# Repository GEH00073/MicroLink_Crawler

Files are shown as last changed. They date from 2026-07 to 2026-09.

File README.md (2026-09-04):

# MicroLink Crawler

English | [日本語](README_ja.md)

**[Grand Prize Winner — M5Stack Global Innovation Contest 2026](https://m5stack.com/global-innovation-contest-2026/results)**

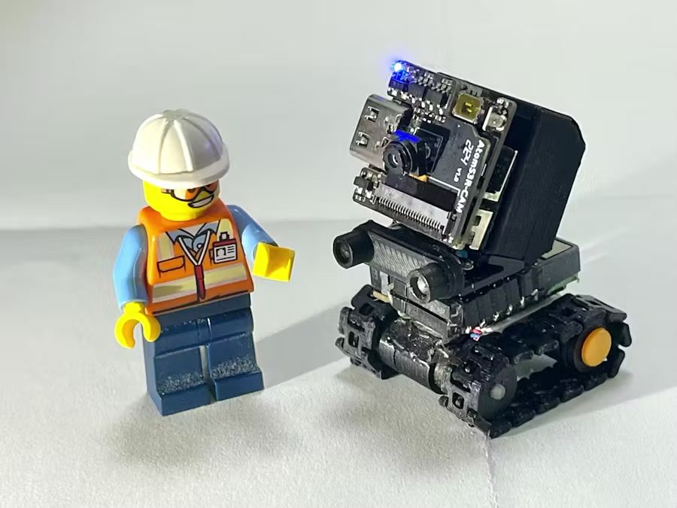
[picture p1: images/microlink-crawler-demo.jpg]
MicroLink Crawler demonstration photo


[▶ Watch the demo video on YouTube](https://www.youtube.com/watch?v=ZiZfx9JVto8)

MicroLink Crawler is a pocket-sized FPV exploration rover centred on a **30 × 30 mm crawler drive module** and 7 mm-wide, 3D-printed linked tracks. A detachable AtomS3R-CAM provides FPV video, orientation data, and red-object detection; an M5Stack Core2 acts as the remote monitor and an Atom JoyStick as the wireless controller.

This repository is a project archive, not a complete reproduction manual. Mechanical fit, printing results, and electronic assembly can require adjustment for the parts and tools in use.

## Highlights

- 30 × 30 mm crawler drive module
- Functional 7 mm-wide 3D-printed linked tracks
- 6 mm-diameter planetary geared motors
- Detachable AtomS3R-CAM module
- Live MJPEG FPV video
- Real-time heading and tilt display on Core2
- Red-object detection with a bounding box and centre coordinates
- Wireless operation with Atom JoyStick
- The complete system fits in a book-sized carrying case

## System overview

```mermaid
flowchart TB
  Joy["Atom JoyStick<br/>Controller"] -->|"ESP-NOW / ch 1"| Pico["M5Stamp Pico<br/>Crawler control"]
  Pico --> Motors["Two geared motors<br/>Micro linked tracks"]
  Camera["AtomS3R-CAM<br/>FPV + IMU + detection"] -->|"MJPEG / Wi-Fi AP ch 3"| Core2["M5Stack Core2<br/>Remote monitor"]
  Camera -->|"ESP-NOW / ch 3"| Core2
```

The system separates two wireless functions: Atom JoyStick sends crawler-control packets to Stamp Pico over ESP-NOW on Wi-Fi channel 1, while AtomS3R-CAM provides the camera/Core2 function on channel 3. The camera serves MJPEG through its access point and sends IMU data to Core2 through ESP-NOW.

Read more: [system overview](docs/system-overview.md).

## Micro linked tracks

The 7 mm-wide linked tracks were developed by progressively reducing a larger prototype. They were made with a standard 0.4 mm-nozzle FDM printer. A centre guide groove and openings that engage the sprocket teeth help keep the track aligned, transfer torque, and reduce derailment or slip. The drive uses 6 mm-diameter planetary geared motors.

Read more: [micro linked tracks](docs/micro-linked-track.md).

## FPV, orientation, and red-object detection

The AtomS3R-CAM serves MJPEG video to Core2 through its Wi-Fi access point. Its IMU data is sent to Core2 over ESP-NOW, where heading and tilt are displayed. The camera firmware also detects red objects and sends the detection-box centre coordinates.

The Core2 monitor disables Wi-Fi power saving while streaming and favours the latest decoded frame when old frames must be dropped. On the camera side, a 350 ms TCP send timeout limits how long a slow client can hold up streaming work. These measures are intended to reduce prolonged video stalls.

Read more: [vision and telemetry](docs/vision-and-telemetry.md).

## Firmware

Each directory below is an independent PlatformIO project.

| Directory | Hardware | Role | Communication partner |
| --- | --- | --- | --- |
| `Firmware/MC_stamp_pico_crawler` | M5Stamp Pico | Controls the two motors and lights | Atom JoyStick |
| `Firmware/MC_AtomJoystick` | AtomS3 with Atom JoyStick Base | Remote control | M5Stamp Pico |
| `Firmware/MC_AtomS3R_CAM_GC0308_gylo` | AtomS3R-CAM with GC0308 | FPV, IMU, and red-object detection | Core2 |
| `Firmware/MC_Core2_cam_reciever_AP` | M5Stack Core2 | Video and orientation-information display | AtomS3R-CAM |

Read more: [firmware overview](docs/firmware-overview.md).

## 3D data

[`3D_Printer_Data/`](3D_Printer_Data/) contains STL files for printing and Fusion 360 F3D files for design inspection or editing. These are the design data used for the award project and are provided as structural reference data, not as a complete fabrication guide. Printer, material, and dimensional tolerances can require adjustment.

Read more: [3D data guide](3D_Printer_Data/README.md) and [development story](docs/development-story.md).

## Repository layout

| Path | Contents |
| --- | --- |
| `Firmware/` | Four independent PlatformIO firmware projects |
| `3D_Printer_Data/` | STL and Fusion 360 F3D mechanical design data |
| `docs/` | Project, track, vision, development, and firmware notes |

## Links and questions

- [M5Stack Global Innovation Contest 2026 Results](https://m5stack.com/global-innovation-contest-2026/results)
- [Hackster.io project page](https://www.hackster.io/user2729037/microlink-crawler-379ff1)
- [X: @GEH00073](https://x.com/GEH00073)
- [GitHub Issues](https://github.com/GEH00073/MicroLink_Crawler/issues/new)

Please use [GitHub Issues](https://github.com/GEH00073/MicroLink_Crawler/issues/new) first for technical questions so that answers can help other readers. Following or sending a direct message on X is optional.

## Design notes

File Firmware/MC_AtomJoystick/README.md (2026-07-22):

# AtomJoystick Firmware

Dedicated M5AtomS3 controller firmware for the MicroLink Crawler.

## Operation

The firmware starts directly in crawler control mode. It reads the Atom
JoyStick Base and sends BugC-compatible ESP-NOW broadcast packets at 20 Hz on
Wi-Fi channel 1. There is no OTA mode, vehicle-selection menu, Toio support,
or controller-side pairing procedure.

Use it with `MC_stamp_pico_crawler`. Power on both devices and begin control.

## Build and upload

Open this directory as a PlatformIO project, select the `m5stack-atoms3`
environment, and upload over USB.

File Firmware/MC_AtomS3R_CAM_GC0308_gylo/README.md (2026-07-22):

# AtomS3R Camera Transmitter

PlatformIO firmware for an AtomS3R with a GC0308 camera.

## Features

- Creates a Wi-Fi access point and serves an MJPEG stream at `/video`.
- Sends IMU data through ESP-NOW at 10 Hz.
- Detects red objects and draws a 2-pixel green bounding box at 10 Hz.
- Uses a bounded TCP send timeout so a slow client cannot stop camera capture
  or IMU transmission for several seconds.

## Network settings

| Setting | Value |
| --- | --- |
| SSID | `AtomS3R_CAM` |
| Password | `123456` |
| Wi-Fi channel | 3 |
| Access point address | `192.168.4.1` |
| Stream URL | `http://192.168.4.1/video` |

The Core2 monitor firmware is configured to use these same settings. Change
the `AP_SSID` and `AP_PASSWORD` constants in `src/main.cpp`, and make the
matching change in the Core2 firmware, if different credentials are required.

## Build and upload

Open this directory as a PlatformIO project and use the `m5stack-atoms3r`
environment. Upload over USB.

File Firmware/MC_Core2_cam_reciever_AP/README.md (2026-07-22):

# Core2 Camera Monitor

PlatformIO firmware for an M5Stack Core2 used as the MicroLink Crawler camera
monitor.

## Operation

The monitor connects to the AtomS3R camera access point and displays the MJPEG
stream from `http://192.168.4.1/video`. It also receives and displays IMU data
from the camera through ESP-NOW.

The expected camera network is:

| Setting | Value |
| --- | --- |
| SSID | `AtomS3R_CAM` |
| Password | `123456` |

Wi-Fi power saving is disabled while streaming. The receiver discards old
frames when necessary so the display follows the most recent decoded frame.

## Build and upload

Open this directory as a PlatformIO project, select the `m5stack-core2`
environment, and upload over USB.

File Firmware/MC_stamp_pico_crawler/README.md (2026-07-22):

# Stamp Pico Crawler Firmware

PlatformIO firmware for the M5Stamp Pico installed in the MicroLink Crawler.

## Control link

The crawler receives 25-byte BugC-compatible control packets through ESP-NOW
on Wi-Fi channel 1. `MC_AtomJoystick` sends these packets as broadcast frames,
so the joystick can control the crawler immediately after both devices are
powered on. No controller-side pairing menu or saved peer address is needed.

The packet carries rudder, throttle, aileron, elevator, four button states,
and a checksum. The crawler validates the packet length, destination, and
checksum before applying it.

## Build and upload

Open this directory as a PlatformIO project and upload it to the Stamp Pico
over USB.

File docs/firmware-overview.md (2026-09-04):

# Firmware overview

English | [日本語](firmware-overview_ja.md)

The repository contains four independent PlatformIO projects. Build and upload each project from its own directory.

| Project | Hardware | Main role | Communication partner |
| --- | --- | --- | --- |
| [`Firmware/MC_stamp_pico_crawler`](../Firmware/MC_stamp_pico_crawler/) | M5Stamp Pico | Receives BugC-compatible ESP-NOW control packets on channel 1; controls two motors and lights | `MC_AtomJoystick` |
| [`Firmware/MC_AtomJoystick`](../Firmware/MC_AtomJoystick/) | AtomS3 with Atom JoyStick Base | Sends BugC-compatible ESP-NOW control packets on channel 1 | `MC_stamp_pico_crawler` |
| [`Firmware/MC_AtomS3R_CAM_GC0308_gylo`](../Firmware/MC_AtomS3R_CAM_GC0308_gylo/) | AtomS3R with GC0308 camera | Camera access point, MJPEG FPV, IMU transmission, and red-object detection on channel 3 | `MC_Core2_cam_reciever_AP` |
| [`Firmware/MC_Core2_cam_reciever_AP`](../Firmware/MC_Core2_cam_reciever_AP/) | M5Stack Core2 | Receives and displays MJPEG video and IMU information | `MC_AtomS3R_CAM_GC0308_gylo` |

The control and camera systems are separate: do not confuse the crawler-control channel 1 with the camera/Core2 channel 3. Consult each project’s existing README and `platformio.ini` for its build configuration.

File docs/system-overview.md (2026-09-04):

# System overview

English | [日本語](system-overview_ja.md)

MicroLink Crawler combines a 30 × 30 mm crawler drive module, a detachable AtomS3R-CAM module, an Atom JoyStick controller, a Core2 monitor, and a book-sized carrying case for the complete system.

The drive-control and camera-monitor functions use separate Wi-Fi channels so their roles remain distinct:

| Path | Devices | Function |
| --- | --- | --- |
| Control | Atom JoyStick → M5Stamp Pico | ESP-NOW crawler control on channel 1 |
| Video | AtomS3R-CAM → Core2 | MJPEG through the camera access point on channel 3 |
| Telemetry | AtomS3R-CAM → Core2 | IMU data through ESP-NOW on channel 3 |

The Stamp Pico controls the two geared motors and lights. The camera module can be removed from the drive module; Core2 displays video and orientation information remotely.

See the [README](../README.md) for the system diagram and [firmware overview](firmware-overview.md) for project locations.

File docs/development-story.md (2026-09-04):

# Development story

English | [日本語](development-story_ja.md)

The public project description records the following development progression:

1. An initial larger linked-track prototype.
2. Progressive miniaturisation to a 7 mm-wide linked track.
3. Drive by 6 mm-diameter planetary geared motors.
4. Wireless crawler control with Stamp Pico and Atom JoyStick.
5. Detachable AtomS3R-CAM FPV capability.
6. Core2 display of video plus orientation information.
7. Red-object detection and centre-coordinate display.
8. A complete system that fits in a book-sized carrying case.
9. Entry in the M5Stack Global Innovation Contest 2026 and Grand Prize recognition.

The public sources and repository do not establish a detailed chronology, design motivation, failed experiments, or fabrication conditions beyond these points. Those subjects are intentionally not reconstructed here.

Sources: [M5Stack contest results](https://m5stack.com/global-innovation-contest-2026/results) and the [Hackster.io project page](https://www.hackster.io/user2729037/microlink-crawler-379ff1).

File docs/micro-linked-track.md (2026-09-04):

# Micro linked tracks

English | [日本語](micro-linked-track_ja.md)

The micro linked-track system was developed by progressively reducing a larger prototype until it reached a 7 mm track width. It is a functional track system printed with a standard 0.4 mm-nozzle FDM printer and driven by 6 mm-diameter planetary geared motors.

A guide groove along the centre of each track works with openings shaped for the sprocket teeth. Together, these features keep the track aligned, transmit drive torque, and reduce derailment or slip.

This document is a design note, not a complete manufacturing procedure. It does not prescribe material, print settings, tolerances, or an assembly sequence; those depend on the equipment and parts used.

See the [3D data guide](../3D_Printer_Data/README.md) for the supplied STL and F3D data, and the [development story](development-story.md) for the confirmed project progression.

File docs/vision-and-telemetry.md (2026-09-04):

# Vision and telemetry

English | [日本語](vision-and-telemetry_ja.md)

The detachable AtomS3R-CAM module creates a Wi-Fi access point on channel 3 and serves an MJPEG stream at `/video`. Core2 connects to that access point and displays the video.

The camera firmware sends IMU data through ESP-NOW on channel 3 at 10 Hz. Core2 uses that information to display heading and tilt. The camera also performs red-object detection; when a red object is detected, the system supplies a green detection box and its centre coordinates to the monitor.

Two implementation choices reduce visible latency or long pauses:

- Core2 disables Wi-Fi power saving while streaming and discards older frames when necessary so the latest decoded frame is preferred.
- The camera uses a 350 ms TCP send timeout, limiting how long a slow client can hold up streaming work.

For settings and build targets, see the [camera firmware README](../Firmware/MC_AtomS3R_CAM_GC0308_gylo/README.md) and [Core2 firmware README](../Firmware/MC_Core2_cam_reciever_AP/README.md).

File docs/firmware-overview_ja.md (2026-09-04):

# ファームウェア構成

[English](firmware-overview.md) | 日本語

リポジトリには4つの独立したPlatformIOプロジェクトがあります。各プロジェクトはそれぞれのディレクトリからビルド・書き込みを行います。

| プロジェクト | ハードウェア | 主な役割 | 通信相手 |
| --- | --- | --- | --- |
| [`Firmware/MC_stamp_pico_crawler`](../Firmware/MC_stamp_pico_crawler/) | M5Stamp Pico | チャンネル1でBugC互換ESP-NOW制御パケットを受信し、2台のモーターとライトを制御 | `MC_AtomJoystick` |
| [`Firmware/MC_AtomJoystick`](../Firmware/MC_AtomJoystick/) | AtomS3 + Atom JoyStick Base | チャンネル1でBugC互換ESP-NOW制御パケットを送信 | `MC_stamp_pico_crawler` |
| [`Firmware/MC_AtomS3R_CAM_GC0308_gylo`](../Firmware/MC_AtomS3R_CAM_GC0308_gylo/) | AtomS3R + GC0308カメラ | チャンネル3のカメラアクセスポイント、MJPEG FPV、IMU送信、赤色物体検出 | `MC_Core2_cam_reciever_AP` |
| [`Firmware/MC_Core2_cam_reciever_AP`](../Firmware/MC_Core2_cam_reciever_AP/) | M5Stack Core2 | MJPEG映像とIMU情報を受信・表示 | `MC_AtomS3R_CAM_GC0308_gylo` |

走行制御系とカメラ系は別です。走行制御のチャンネル1と、カメラ／Core2のチャンネル3を混同しないでください。ビルド設定は各プロジェクトの既存READMEおよび`platformio.ini`を参照してください。

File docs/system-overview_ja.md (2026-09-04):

# システム構成

[English](system-overview.md) | 日本語

MicroLink Crawlerは、30 × 30 mmのクローラー走行モジュール、着脱可能なAtomS3R-CAMモジュール、Atom JoyStickコントローラー、Core2モニター、およびシステム全体を収納するブックサイズの携帯ケースで構成されます。

走行制御とカメラ・モニターの機能は、それぞれの役割を分けるため別のWi-Fiチャンネルを使用します。

| 経路 | デバイス | 機能 |
| --- | --- | --- |
| 走行制御 | Atom JoyStick → M5Stamp Pico | チャンネル1のESP-NOWによる走行制御 |
| 映像 | AtomS3R-CAM → Core2 | チャンネル3のカメラアクセスポイント経由MJPEG |
| テレメトリー | AtomS3R-CAM → Core2 | チャンネル3のESP-NOWによるIMU情報 |

Stamp Picoは2台のギヤードモーターとライトを制御します。カメラモジュールは走行モジュールから取り外せ、Core2は遠隔で映像と姿勢情報を表示します。

システム図は[README](../README_ja.md)、プロジェクトの配置は[ファームウェア構成](firmware-overview_ja.md)を参照してください。

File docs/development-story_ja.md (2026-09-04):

# 開発の経緯

[English](development-story.md) | 日本語

公開されている作品説明から、次の開発の流れを確認できます。

1. 大きなリンク式履帯による初期試作。
2. 7 mm幅のリンク式履帯までの段階的な小型化。
3. 6 mm径の遊星ギヤードモーターによる駆動。
4. Stamp PicoとAtom JoyStickによる無線走行制御。
5. 着脱可能なAtomS3R-CAMによるFPV機能。
6. 映像と姿勢情報をCore2へ表示。
7. 赤色物体検出と中心座標表示。
8. システム全体をブックサイズの携帯ケースへ収納。
9. M5Stack Global Innovation Contest 2026への応募とGrand Prize受賞。

公開情報とリポジトリからは、これらより詳細な時系列、設計動機、失敗した試作、製作条件までは確認できません。これらの事項は推測で再構成していません。

情報源: [M5Stackコンテスト結果](https://m5stack.com/global-innovation-contest-2026/results)および[Hackster.io作品ページ](https://www.hackster.io/user2729037/microlink-crawler-379ff1)。

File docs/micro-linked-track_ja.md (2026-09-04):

# マイクロリンク式履帯

[English](micro-linked-track.md) | 日本語

マイクロリンク式履帯は、大型試作を段階的に縮小し、7 mm幅に到達するまで開発されました。一般的な0.4 mmノズルのFDMプリンターで造形した、機能する履帯システムであり、6 mm径の遊星ギヤードモーターで駆動します。

各履帯の中央ガイド溝と、スプロケット歯に合わせた開口部が連携します。これにより履帯の位置を保ち、駆動トルクを伝達して、外れや空転を抑えます。

本書は設計の補足であり、完全な製作手順ではありません。材料、印刷設定、寸法公差、組み立て順序は、使用する機器と部品に依存するため規定していません。

収録したSTL・F3Dデータは[3Dデータガイド](../3D_Printer_Data/README_ja.md)、確認済みの開発経緯は[開発の経緯](development-story_ja.md)を参照してください。

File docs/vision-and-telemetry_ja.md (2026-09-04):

# FPV・姿勢情報・赤色物体検出

[English](vision-and-telemetry.md) | 日本語

着脱可能なAtomS3R-CAMモジュールはチャンネル3でWi-Fiアクセスポイントを作成し、`/video`でMJPEGストリームを配信します。Core2はこのアクセスポイントに接続して映像を表示します。

カメラのファームウェアは、チャンネル3のESP-NOWでIMU情報を10 Hzで送信します。Core2はこの情報を用いて方位と傾きを表示します。カメラは赤色物体も検出し、検出時には緑色の検出枠と中心座標をモニターへ送ります。

可視遅延や長い停止を抑えるため、実装には次の処理があります。

- Core2はストリーミング中にWi-Fi省電力を無効化し、必要に応じて古いフレームを捨てて最新のデコード済みフレームを優先します。
- カメラは350 msのTCP送信タイムアウトを使用し、遅いクライアントがストリーミング処理を占有する時間を制限します。

設定とビルド対象は、[カメラファームウェアREADME](../Firmware/MC_AtomS3R_CAM_GC0308_gylo/README.md)および[Core2ファームウェアREADME](../Firmware/MC_Core2_cam_reciever_AP/README.md)を参照してください。

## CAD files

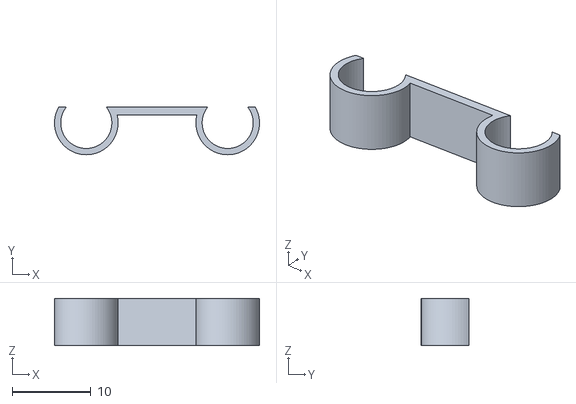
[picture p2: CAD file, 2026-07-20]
3D_Printer_Data/chassis.stl
26.1 x 6.05 x 6.00

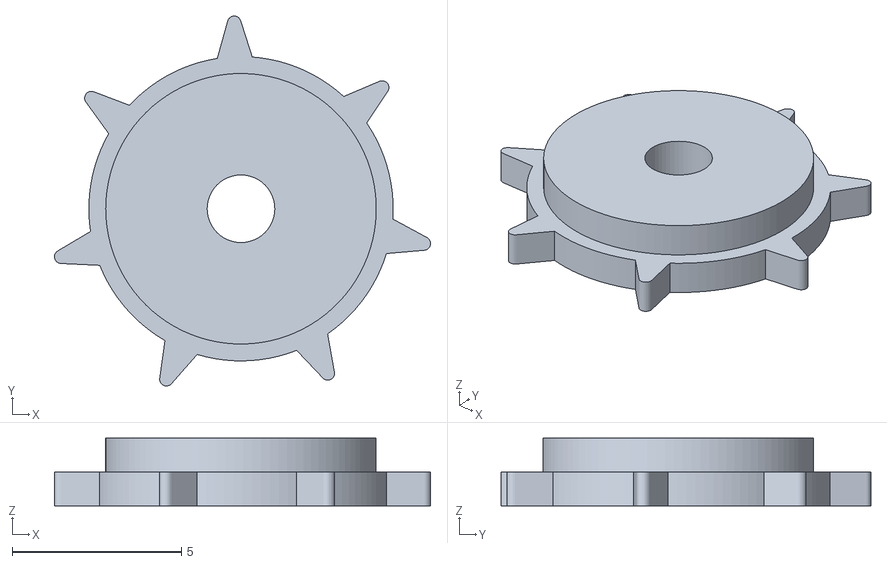
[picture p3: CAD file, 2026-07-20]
3D_Printer_Data/sprocket_9mm.stl
11.1 x 10.9 x 2.00

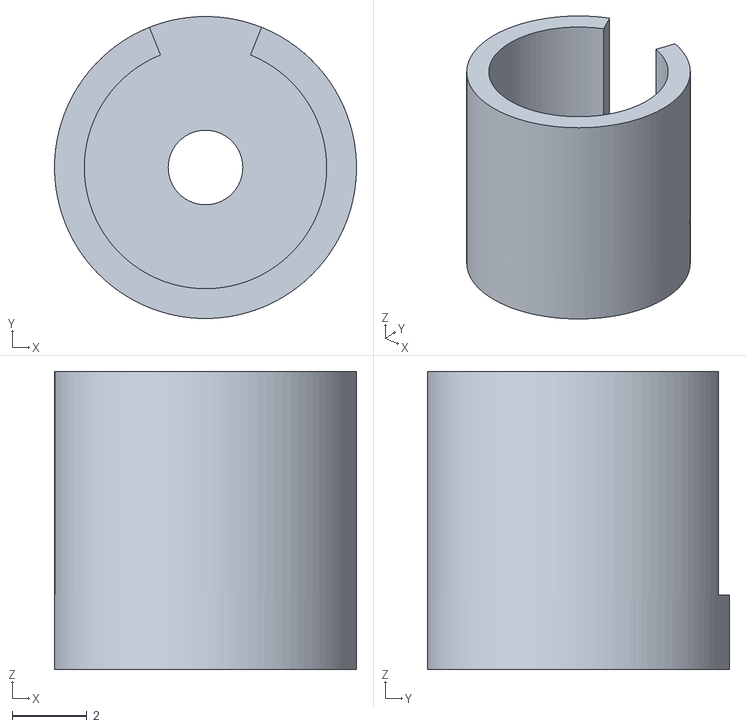
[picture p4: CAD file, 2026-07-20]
3D_Printer_Data/motor_bottom.stl
8.10 x 8.10 x 8.00

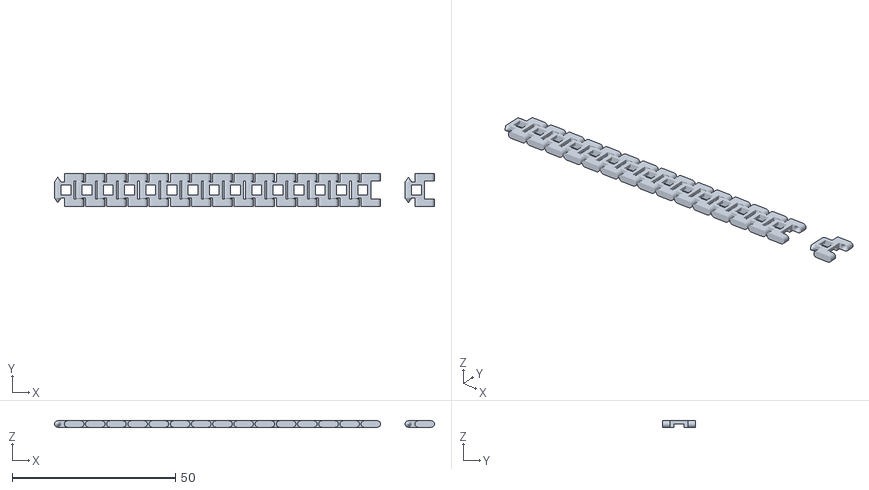
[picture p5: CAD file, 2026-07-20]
3D_Printer_Data/hinge_s.stl
116.5 x 10.0 x 2.00

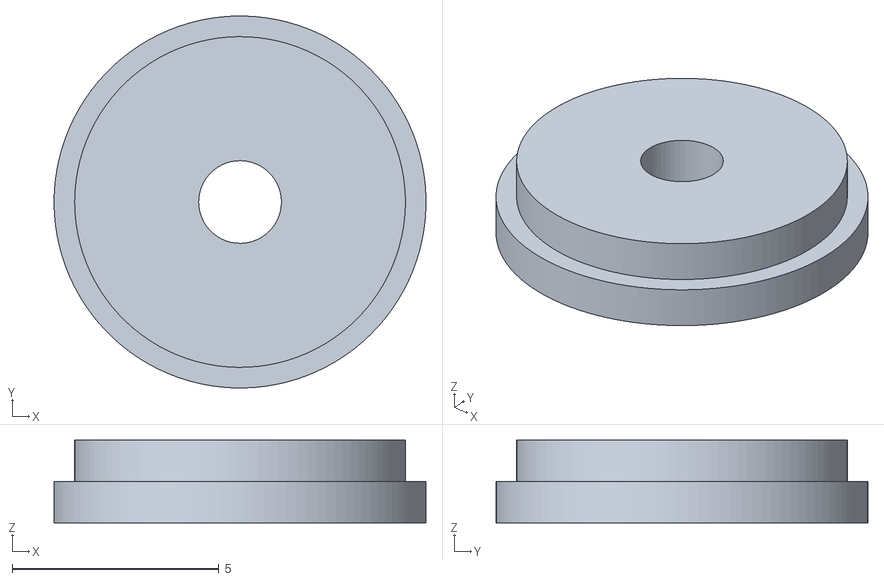
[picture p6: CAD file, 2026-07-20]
3D_Printer_Data/sprocket_9mm_2.stl
9.00 x 9.00 x 2.00

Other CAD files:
3D_Printer_Data/chassis.f3d
3D_Printer_Data/hinge_s.f3d
3D_Printer_Data/motor_bottom.f3d
3D_Printer_Data/sprocket_9mm.f3d
3D_Printer_Data/sprocket_9mm_2.f3d

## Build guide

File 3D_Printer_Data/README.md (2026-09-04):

# MicroLink Crawler 3D Data

English | [日本語](README_ja.md)

This directory contains the STL printing files and Fusion 360 F3D design files used for the MicroLink Crawler award project. STL files are intended for printing; F3D files are provided for design inspection or editing.

These files are structural reference data, not a complete fabrication manual. Printing and assembly can require adjustment for the printer, material, component tolerances, and tools in use.

| File | Format | Description |
| --- | --- | --- |
| `chassis.stl` / `chassis.f3d` | STL / F3D | Chassis design data |
| `hinge_s.stl` / `hinge_s.f3d` | STL / F3D | Hinge design data |
| `motor_bottom.stl` / `motor_bottom.f3d` | STL / F3D | Motor-bottom design data |
| `sprocket_9mm.stl` / `sprocket_9mm.f3d` | STL / F3D | Sprocket design data |
| `sprocket_9mm_2.stl` / `sprocket_9mm_2.f3d` | STL / F3D | Sprocket design data |

For the project context and track design notes, see the [root README](../README.md) and [micro linked tracks](../docs/micro-linked-track.md).

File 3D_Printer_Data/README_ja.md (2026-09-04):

# MicroLink Crawler 3Dデータ

[English](README.md) | 日本語

このディレクトリには、MicroLink Crawler受賞作品で使用したSTL造形データとFusion 360 F3D設計データを収録しています。STLは造形用、F3Dは設計確認・編集用のデータです。

これらは構造を確認するための参考データであり、完全な製作マニュアルではありません。プリンター、材料、部品の寸法公差、工具に応じて、造形や組み立ての調整が必要になる場合があります。

| ファイル | 形式 | 説明 |
| --- | --- | --- |
| `chassis.stl` / `chassis.f3d` | STL / F3D | シャーシ設計データ |
| `hinge_s.stl` / `hinge_s.f3d` | STL / F3D | ヒンジ設計データ |
| `motor_bottom.stl` / `motor_bottom.f3d` | STL / F3D | モーター下部の設計データ |
| `sprocket_9mm.stl` / `sprocket_9mm.f3d` | STL / F3D | スプロケット設計データ |
| `sprocket_9mm_2.stl` / `sprocket_9mm_2.f3d` | STL / F3D | スプロケット設計データ |

作品全体と履帯設計の説明は、[ルートREADME](../README_ja.md)および[マイクロリンク式履帯](../docs/micro-linked-track_ja.md)を参照してください。

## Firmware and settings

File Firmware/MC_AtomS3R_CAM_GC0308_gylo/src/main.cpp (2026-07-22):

#include <Wire.h>
#include <WiFi.h>
#include <esp_http_server.h>
#include <esp_camera.h>
#include <esp_now.h>
#include <lwip/sockets.h>

// ==== BMI270 (Bosch API) ====
#include "bmi270.h"
#include "bmi2.h"

#define BMI270_ADDR 0x68

struct bmi2_dev bmi2_dev;
struct bmi2_sens_config sens_cfg[2];
struct bmi2_sens_data sensor_data[2];

// ==== Wi-Fi AP ====
// Core2 receiver connects directly to this access point.
const char *AP_SSID = "AtomS3R_CAM";
const char *AP_PASSWORD = "123456";
constexpr uint8_t WIFI_CHANNEL = 3;
const IPAddress AP_IP(192, 168, 4, 1);
const IPAddress AP_GATEWAY(192, 168, 4, 1);
const IPAddress AP_SUBNET(255, 255, 255, 0);

typedef struct struct_message {
  int16_t x;
  int16_t y;
  float ax, ay, az;
  float gx, gy, gz;
} struct_message;
struct_message myData;

uint8_t broadcastAddress[] = {0xFF,0xFF,0xFF,0xFF,0xFF,0xFF};

float ax, ay, az;
float gx, gy, gz;
float cx_smooth = 0;
float cy_smooth = 0;
bool first_point = true;
unsigned long last_imu_send_ms = 0;
constexpr unsigned long IMU_SEND_INTERVAL_MS = 100; // 10 Hz
unsigned long last_box_draw_ms = 0;
constexpr unsigned long BOX_DRAW_INTERVAL_MS = 100; // 10 Hz
constexpr bool ENABLE_RED_DETECTION = true;
constexpr long STREAM_SEND_TIMEOUT_US = 350000; // TCP詰まりを350 msで打ち切る
portMUX_TYPE imu_data_mux = portMUX_INITIALIZER_UNLOCKED;

volatile uint32_t diag_espnow_ok = 0;
volatile uint32_t diag_espnow_fail = 0;
uint32_t diag_stream_frames = 0;
uint32_t diag_stream_bytes = 0;
uint32_t diag_max_encode_us = 0;
uint32_t diag_max_send_us = 0;
uint32_t diag_last_frame_ms = 0;
uint32_t diag_last_report_ms = 0;

// ==== Bosch API用のI2Cラッパ ====

// 書き込み
BMI2_INTF_RETURN_TYPE i2c_reg_write(uint8_t reg_addr, const uint8_t *reg_data, uint32_t length, void *intf_ptr) {
  Wire.beginTransmission(BMI270_ADDR);
  Wire.write(reg_addr);
  Wire.write(reg_data, length);
  return (Wire.endTransmission() == 0) ? BMI2_INTF_RET_SUCCESS : BMI2_E_COM_FAIL;
}

// 読み込み
BMI2_INTF_RETURN_TYPE i2c_reg_read(uint8_t reg_addr, uint8_t *reg_data, uint32_t length, void *intf_ptr) {
  Wire.beginTransmission(BMI270_ADDR);
  Wire.write(reg_addr);
  Wire.endTransmission(false);
  Wire.requestFrom((uint16_t)BMI270_ADDR, (uint8_t)length);
  for (uint32_t i = 0; i < length; i++) {
    reg_data[i] = Wire.read();
  }
  return BMI2_INTF_RET_SUCCESS;
}

void bmi2_delay_us(uint32_t period, void *intf_ptr) {
  delayMicroseconds(period);
}

// ==== BMI270 初期化 ====
void init_bmi270() {
  bmi2_dev.intf = BMI2_I2C_INTF;
  bmi2_dev.read = i2c_reg_read;
  bmi2_dev.write = i2c_reg_write;
  bmi2_dev.delay_us = bmi2_delay_us;
  bmi2_dev.intf_ptr = NULL;
  bmi2_dev.read_write_len = 32;
  bmi2_dev.config_file_ptr = NULL;

  int8_t rslt = bmi270_init(&bmi2_dev);
  if (rslt != BMI2_OK) {
    Serial.printf("BMI270 init failed: %d\n", rslt);
    return;
  }

  uint8_t sens_list[2] = { BMI2_ACCEL, BMI2_GYRO };
  bmi2_sensor_enable(sens_list, 2, &bmi2_dev);

  sens_cfg[0].type = BMI2_ACCEL;
  sens_cfg[1].type = BMI2_GYRO;
  bmi2_get_sensor_config(sens_cfg, 2, &bmi2_dev);

  sens_cfg[0].cfg.acc.odr = BMI2_ACC_ODR_100HZ;
  sens_cfg[0].cfg.acc.range = BMI2_ACC_RANGE_8G;
  sens_cfg[1].cfg.gyr.odr = BMI2_GYR_ODR_100HZ;
  sens_cfg[1].cfg.gyr.range = BMI2_GYR_RANGE_2000;

  bmi2_set_sensor_config(sens_cfg, 2, &bmi2_dev);
  Serial.println("BMI270 init OK");
}

// ==== 加速度・ジャイロ読み出し（最新ライブラリ対応） ====
void readAccelGyro() {
  int8_t rslt;

  // LSB換算値
  const float ACC_LSB_8G   = 8.0f / 32768.0f;     // ±2G
  const float GYR_LSB_2000 = 2000.0f / 32768.0f;  // ±2000 dps

  // 加速度取得
  rslt = bmi2_get_sensor_data(&sensor_data[0], &bmi2_dev);
  if (rslt != BMI2_OK) return;
  ax = sensor_data[0].acc.x * ACC_LSB_8G;
  ay = sensor_data[0].acc.y * ACC_LSB_8G;
  az = sensor_data[0].acc.z * ACC_LSB_8G;

  // ジャイロ取得
  rslt = bmi2_get_sensor_data(&sensor_data[1], &bmi2_dev);
  if (rslt != BMI2_OK) return;
  gx = sensor_data[1].gyr.x * GYR_LSB_2000;
  gy = sensor_data[1].gyr.y * GYR_LSB_2000;
  gz = sensor_data[1].gyr.z * GYR_LSB_2000;
}

// ==== ESP-NOW送信コールバック ====
void OnDataSent(const uint8_t *mac_addr, esp_now_send_status_t status) {
  if (status == ESP_NOW_SEND_SUCCESS) diag_espnow_ok++;
  else diag_espnow_fail++;
}

// ==== MJPEG ====
#define PART_BOUNDARY "123456789000000000000987654321"
static const char* _STREAM_CONTENT_TYPE = "multipart/x-mixed-replace;boundary=" PART_BOUNDARY;
static const char* _STREAM_BOUNDARY = "\r\n--" PART_BOUNDARY "\r\n";
static const char* _STREAM_PART = "Content-Type: image/jpeg\r\nContent-Length: %u\r\n\r\n";

uint8_t* out_jpg   = NULL;
size_t out_jpg_len = 0;

// ==== 緑の2画素枠を描画 ====
void draw_green_rect(camera_fb_t *fb, int x_min, int y_min, int x_max, int y_max) {
  if (x_min < 0 || y_min < 0 || x_max >= fb->width || y_max >= fb->height) return;
  uint16_t green = (63 << 5);
  for (int thickness = 0; thickness < 2; ++thickness) {
    const int left_x = x_min + thickness;
    const int right_x = x_max - thickness;
    const int top_y = y_min + thickness;
    const int bottom_y = y_max - thickness;
    if (left_x > right_x || top_y > bottom_y) break;

    for (int x = left_x; x <= right_x; ++x) {
      size_t top = (top_y * fb->width + x) * 2;
      size_t bottom = (bottom_y * fb->width + x) * 2;
      fb->buf[top] = fb->buf[bottom] = green >> 8;
      fb->buf[top + 1] = fb->buf[bottom + 1] = green & 0xFF;
    }
    for (int y = top_y; y <= bottom_y; ++y) {
      size_t left = (y * fb->width + left_x) * 2;
      size_t right = (y * fb->width + right_x) * 2;
      fb->buf[left] = fb->buf[right] = green >> 8;
      fb->buf[left + 1] = fb->buf[right + 1] = green & 0xFF;
    }
  }
}

// ==== 色検出処理 ====
void Color_detection(camera_fb_t *fb){
  int16_t detected_x = 0;
  int16_t detected_y = 0;
  if (ENABLE_RED_DETECTION) {
  int count[] = {0,0,0,0};
  int height = fb->height;
  int width  = fb->width;
  int y_min = 1000, y_max = -1000;
  int x_min = 1000, x_max = -1000;

  for(int y=0;y<height;y++){
    for(int x=0;x<width;x++){
      size_t idx=(y*width+x)*2;
      uint16_t pixel=(fb->buf[idx]<<8)|(fb->buf[idx+1]);
      uint8_t r=((pixel>>11)&0x1F)<<3;
      uint8_t g=((pixel>>5)&0x3F)<<2;
      uint8_t b=(pixel&0x1F)<<3;

      if(r>200 && g<100 && b<100){
        if(x<width/3) count[0]++; else if(x>width/3*2) count[1]++;
        if(y<height/3) count[2]++; else if(y>height/3*2) count[3]++;

        if(x_min>x) x_min=x; if(x_max<x) x_max=x;
        if(y_min>y) y_min=y; if(y_max<y) y_max=y;
      }
    }
  }

  if(x_min<x_max && y_min<y_max){
    int cx=(x_min+x_max)/2;
    int cy=(y_min+y_max)/2;

    if(first_point){
      cx_smooth=cx; cy_smooth=cy; first_point=false;
    } else {
      float alpha=0.2;
      cx_smooth=cx_smooth*(1-alpha)+cx*alpha;
      cy_smooth=cy_smooth*(1-alpha)+cy*alpha;
    }
    if (millis() - last_box_draw_ms >= BOX_DRAW_INTERVAL_MS) {
      draw_green_rect(fb, x_min, y_min, x_max, y_max);
      last_box_draw_ms = millis();
    }
    detected_x=(int)cx_smooth;
    detected_y=(int)cy_smooth;
  }
  }

  portENTER_CRITICAL(&imu_data_mux);
  myData.x = detected_x;
  myData.y = detected_y;
  portEXIT_CRITICAL(&imu_data_mux);
}

// HTTP送信が停止してもIMU/ESP-NOWを10 Hzで継続する。
void serviceImuEspNow() {
  const unsigned long now = millis();
  if (now - last_imu_send_ms < IMU_SEND_INTERVAL_MS) return;
  last_imu_send_ms = now;

  readAccelGyro();

  struct_message packet;
  portENTER_CRITICAL(&imu_data_mux);
  myData.ax=ax; myData.ay=ay; myData.az=az;
  myData.gx=gx; myData.gy=gy; myData.gz=gz;
  packet = myData;
  portEXIT_CRITICAL(&imu_data_mux);

  if (esp_now_send(broadcastAddress,(uint8_t*)&packet,sizeof(packet)) != ESP_OK) {
    diag_espnow_fail++;
  }
}

// ==== ストリームハンドラ ====
static esp_err_t stream_handler(httpd_req_t *req){
  camera_fb_t *fb=NULL;
  esp_err_t res=ESP_OK;
  char part_buf[64];

  res=httpd_resp_set_type(req,_STREAM_CONTENT_TYPE);
  if(res!=ESP_OK) return res;

  // Core2側のTCP受信が詰まった場合、何秒もカメラ処理を止めず接続を閉じる。
  const int sockfd = httpd_req_to_sockfd(req);
  struct timeval send_timeout = {};
  send_timeout.tv_usec = STREAM_SEND_TIMEOUT_US;
  if (setsockopt(sockfd, SOL_SOCKET, SO_SNDTIMEO,
                 &send_timeout, sizeof(send_timeout)) != 0) {
    Serial.printf("[CAM][WARN] SO_SNDTIMEO failed errno=%d\n", errno);
  }

  const int frame_interval_ms=1000/30;

  while(true){
    unsigned long start_time=millis();
    if (diag_last_frame_ms != 0 && start_time - diag_last_frame_ms >= 500) {
      Serial.printf("[CAM][FRAME_GAP] gap=%lums heap=%u psram=%u\n",
                    start_time - diag_last_frame_ms, ESP.getFreeHeap(), ESP.getFreePsram());
    }
    diag_last_frame_ms = start_time;
    fb=esp_camera_fb_get();
    if(!fb){Serial.println("Camera capture failed"); res=ESP_FAIL;}
    
    Color_detection(fb);

    const uint32_t encode_start_us = micros();
    free(out_jpg);
    bool jpeg_converted=frame2jpg(fb,80,&out_jpg,&out_jpg_len);
    const uint32_t encode_us = micros() - encode_start_us;
    if (encode_us > diag_max_encode_us) diag_max_encode_us = encode_us;
    esp_camera_fb_return(fb);
    fb=NULL;
    if(!jpeg_converted){Serial.println("JPEG compression failed"); res=ESP_FAIL;}

    const uint32_t send_start_us = micros();
    if(res==ESP_OK){
      size_t hlen=snprintf(part_buf,64,_STREAM_PART,out_jpg_len);
      res=httpd_resp_send_chunk(req,part_buf,hlen);
    }
    if(res==ESP_OK) res=httpd_resp_send_chunk(req,(const char*)out_jpg,out_jpg_len);
    if(res==ESP_OK) res=httpd_resp_send_chunk(req,_STREAM_BOUNDARY,strlen(_STREAM_BOUNDARY));
    const uint32_t send_us = micros() - send_start_us;
    if (send_us > diag_max_send_us) diag_max_send_us = send_us;
    if (res != ESP_OK) {
      Serial.printf("[CAM][SEND_ABORT] wait=%luus err=0x%x\n",
                    (unsigned long)send_us, (unsigned int)res);
    }
    diag_stream_frames++;
    diag_stream_bytes += out_jpg_len;

    const uint32_t report_now = millis();
    if (report_now - diag_last_report_ms >= 1000) {
      Serial.printf("[CAM][STAT] fps=%lu kb=%lu encMax=%luus sendMax=%luus "
                    "nowOK=%lu nowFail=%lu heap=%u psram=%u\n",
                    (unsigned long)diag_stream_frames,
                    (unsigned long)(diag_stream_bytes / 1024),
                    (unsigned long)diag_max_encode_us,
                    (unsigned long)diag_max_send_us,
                    (unsigned long)diag_espnow_ok,
                    (unsigned long)diag_espnow_fail,
                    ESP.getFreeHeap(), ESP.getFreePsram());
      diag_stream_frames = 0;
      diag_stream_bytes = 0;
      diag_max_encode_us = 0;
      diag_max_send_us = 0;
      diag_espnow_ok = 0;
      diag_espnow_fail = 0;
      diag_last_report_ms = report_now;
    }
    if(res!=ESP_OK) break;

    unsigned long elapsed=millis()-start_time;
    if(elapsed<frame_interval_ms) vTaskDelay((frame_interval_ms-elapsed)/portTICK_PERIOD_MS);
  }
  return res;
}

// ==== MJPEGサーバ開始 ====
void start_MJPEG_server(){
  httpd_config_t config=HTTPD_DEFAULT_CONFIG();
  config.server_port=80;
  config.uri_match_fn=httpd_uri_match_wildcard;
  config.max_open_sockets=8;
  config.stack_size=8192;
  config.lru_purge_enable=true;
  config.send_wait_timeout=1;

  httpd_handle_t httpd=NULL;
  if(httpd_start(&httpd,&config)==ESP_OK){
    httpd_uri_t stream_uri={ .uri="/video", .method=HTTP_GET, .handler=stream_handler, .user_ctx=NULL };
    httpd_register_uri_handler(httpd,&stream_uri);
  }
}

// ==== Setup ====
void setup() {
  Serial.begin(115200);
  Serial2.begin(115200, SERIAL_8N1, 2, 1);
  Serial2.println("ATOMS3R-CAM");

  Wire.begin(45,0,400000);
  init_bmi270();

  pinMode(18,OUTPUT);
  digitalWrite(18,LOW);
  delay(500);

  camera_config_t config;
  config.ledc_channel=LEDC_CHANNEL_0;
  config.ledc_timer=LEDC_TIMER_0;
  config.pin_d0=3;
  config.pin_d1=42;
  config.pin_d2=46;
  config.pin_d3=48;
  config.pin_d4=4;
  config.pin_d5=17;
  config.pin_d6=11;
  config.pin_d7=13;
  config.pin_xclk=21;
  config.pin_pclk=40;
  config.pin_vsync=10;
  config.pin_href=14;
  config.pin_sccb_sda=12;
  config.pin_sccb_scl=9;
  config.pin_pwdn=-1;
  config.pin_reset=-1;
  config.xclk_freq_hz=25000000;
  config.pixel_format=PIXFORMAT_RGB565;
  config.frame_size=FRAMESIZE_QQVGA;
  config.jpeg_quality=30;
  config.fb_count=3;
  config.grab_mode=CAMERA_GRAB_LATEST;
  config.fb_location=CAMERA_FB_IN_PSRAM;

  esp_err_t err=esp_camera_init(&config);
  if(err!=ESP_OK){Serial.printf("Camera init failed with error 0x%x",err); return;}
  sensor_t *s=esp_camera_sensor_get();
  s->set_hmirror(s,0);

  WiFi.mode(WIFI_AP);
  WiFi.softAPConfig(AP_IP, AP_GATEWAY, AP_SUBNET);
  if (!WiFi.softAP(AP_SSID, AP_PASSWORD, WIFI_CHANNEL)) {
    Serial.println("Failed to start Wi-Fi AP");
    return;
  }
  Serial.printf("Wi-Fi AP started: %s\n", AP_SSID);
  Serial.printf("Stream URL: http://%s/video\n", WiFi.softAPIP().toString().c_str());

  start_MJPEG_server();

  if(esp_now_init()!=ESP_OK){Serial.println("Error initializing ESP-NOW"); return;}
  esp_now_register_send_cb(OnDataSent);

  esp_now_peer_info_t peerInfo={};
  memcpy(peerInfo.peer_addr,broadcastAddress,6);
  peerInfo.channel=WIFI_CHANNEL;
  peerInfo.ifidx=WIFI_IF_AP;
  peerInfo.encrypt=false;
  if (esp_now_add_peer(&peerInfo) != ESP_OK) {
    Serial.println("Failed to add ESP-NOW broadcast peer");
  }
}

void loop() {
  serviceImuEspNow();
  delay(1);
}

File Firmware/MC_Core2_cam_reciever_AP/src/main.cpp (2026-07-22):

#include <M5Unified.h>
#include <WiFi.h>
#include <HTTPClient.h>
#include <TJpg_Decoder.h>
#include <ArduinoJson.h> 
#include <esp_now.h>
#include <esp_wifi.h>

// ===== AtomS3R-CAM AP設定 =====
const char* ssid     = "AtomS3R_CAM";
const char* password = "123456";

// ===== ストリーミングサーバのURL =====
String streamURL = "http://192.168.4.1/video";


// バッファサイズ
#define STREAM_BUFFER_SIZE (300 * 1024)
// 1: Core 0で受信、Core 1で描画 / 0: 従来の単一ループ方式
#define USE_DUAL_CORE_STREAMING 0

static LGFX_Sprite canvas(&M5.Display);   // オフスクリーン描画用バッファ
static LGFX_Sprite text(&M5.Display);   // テキスト描画用バッファ
static LGFX_Sprite lamp(&M5.Display);   // ランプ描画用バッファ

WiFiClient client;
HTTPClient http;
uint8_t* jpgBuf;
size_t jpgBufLen;
uint8_t* latestJpgBuf;
size_t latestJpgLen = 0;
bool latestJpgReady = false;
#if USE_DUAL_CORE_STREAMING
uint8_t* displayJpgBuf;
size_t displayJpgLen = 0;
SemaphoreHandle_t frameBufferMutex = nullptr;
TaskHandle_t streamReceiveTaskHandle = nullptr;
TaskHandle_t streamDisplayTaskHandle = nullptr;
#endif

u_long ptime, ptime2;
int fps;
float angleAccum = 0; // 累積回転角（ラジアン）
unsigned long lastAngleUpdateMs = 0;
constexpr unsigned long IMU_UPDATE_INTERVAL_MS = 100; // 10 Hz

volatile uint32_t diagEspNowPackets = 0;
volatile uint32_t diagLastEspNowMs = 0;
uint32_t diagRxBytes = 0;
uint32_t diagJpegFrames = 0;
uint32_t diagDrawFrames = 0;
uint32_t diagDroppedFrames = 0;
uint32_t diagLastTcpRxMs = 0;
uint32_t diagLastJpegMs = 0;
uint32_t diagLastDrawMs = 0;
uint32_t diagMaxDecodeUs = 0;
uint32_t diagMaxPushUs = 0;
uint32_t diagLastReportMs = 0;
bool diagTcpStallReported = false;

constexpr uint32_t STREAM_STALL_RECONNECT_MS = 2500;
constexpr uint32_t STREAM_START_TIMEOUT_MS = 1500;
constexpr uint32_t STREAM_RECONNECT_RETRY_MS = 500;
uint32_t streamConnectedMs = 0;
uint32_t lastStreamConnectAttemptMs = 0;
uint32_t streamReconnectCount = 0;

// JPEG処理用の状態管理
bool inJPEG = false;
size_t idx = 0;
uint8_t jpegPreviousByte = 0;

#if USE_DUAL_CORE_STREAMING
void streamReceiveTask(void* parameter);
void streamDisplayTask(void* parameter);
#endif

// === esp-nowデータ構造体 ===
typedef struct struct_message {
  int16_t x;
  int16_t y;
  float ax, ay, az;
  float gx, gy, gz;
} struct_message;

struct_message incomingData;

// === ESP-NOW 受信コールバック ===
void OnDataRecv(const uint8_t * mac, const uint8_t *incomingDataBuf, int len) {
  if (len != sizeof(incomingData)) return;
  memcpy(&incomingData, incomingDataBuf, sizeof(incomingData));
  diagEspNowPackets++;
  diagLastEspNowMs = millis();
//   Serial.printf("ESP-NOW RECV -> x:%d y:%d  ax:%.2f ay:%.2f az:%.2f  gx:%.2f gy:%.2f gz:%.2f\n",
//                 incomingData.x, incomingData.y,
//                 incomingData.ax, incomingData.ay, incomingData.az,
//                 incomingData.gx, incomingData.gy, incomingData.gz);
}

// ==== IMU 表示用 ====
int imuLine = 50;   // Y座標開始位置

// ==== JPEG/IMU受信状態管理 ====
bool inHeader = true;       // ヘッダ読み取り中フラグ
String headerLine = "";     // ヘッダ格納用

// =======================
// JPEG描画コールバック
// =======================
static bool tft_output(int16_t x, int16_t y, uint16_t w, uint16_t h,
                       uint16_t* bitmap) {
    if (y >= M5.Display.height()) return 0;
    canvas.pushImage(x, y, w, h, bitmap);
    // M5.Display.pushImage(x, y, w, h, bitmap);
    return 1;
}

// ===== 中央十字線描画 =====
void drawCrosshair() {
    int cx = canvas.width() / 2;
    int cy = canvas.height() / 2;
    int len = 11;
    int gap = 4;

    // 横線
    canvas.drawLine(cx - len, cy - 1, cx - gap, cy - 1, TFT_BLACK);  // 黒影
    canvas.drawLine(cx + gap, cy - 1, cx + len, cy - 1, TFT_BLACK);
    canvas.drawLine(cx - len, cy, cx - gap, cy, TFT_WHITE);          // 白線
    canvas.drawLine(cx + gap, cy, cx + len, cy, TFT_WHITE);

    // 縦線
    canvas.drawLine(cx + 1, cy - len, cx + 1, cy - gap, TFT_BLACK);  // 黒影
    canvas.drawLine(cx + 1, cy + gap, cx + 1, cy + len, TFT_BLACK);
    canvas.drawLine(cx, cy - len, cx, cy - gap, TFT_WHITE);          // 白線
    canvas.drawLine(cx, cy + gap, cx, cy + len, TFT_WHITE);
}

void resetStreamParser() {
    inJPEG = false;
    idx = 0;
    jpegPreviousByte = 0;
    latestJpgLen = 0;
    latestJpgReady = false;
}

bool connectCameraStream() {
    lastStreamConnectAttemptMs = millis();
    http.end();
    client.stop();
    resetStreamParser();

    if (WiFi.status() != WL_CONNECTED) return false;

    http.setReuse(false);
    http.setConnectTimeout(1000);
    http.setTimeout(1000);
    if (!http.begin(client, streamURL)) {
        Serial.println("[CORE][RECONNECT_FAIL] http.begin");
        return false;
    }

    const int httpCode = http.GET();
    if (httpCode != HTTP_CODE_OK) {
        Serial.printf("[CORE][RECONNECT_FAIL] HTTP=%d\n", httpCode);
        http.end();
        client.stop();
        return false;
    }

    client.setNoDelay(true);
    streamConnectedMs = millis();
    diagLastTcpRxMs = 0;
    diagTcpStallReported = false;
    streamReconnectCount++;
    Serial.printf("[CORE][STREAM_CONNECTED] count=%lu\n",
                  (unsigned long)streamReconnectCount);
    return true;
}

void serviceStreamConnection() {
    const uint32_t now = millis();
    const bool hasNoPendingData = client.available() == 0;
    const bool receiveStalled = diagLastTcpRxMs != 0 && hasNoPendingData &&
                                now - diagLastTcpRxMs >= STREAM_STALL_RECONNECT_MS;
    const bool startTimedOut = diagLastTcpRxMs == 0 && streamConnectedMs != 0 &&
                               now - streamConnectedMs >= STREAM_START_TIMEOUT_MS;
    const bool disconnected = !client.connected();

    if (!receiveStalled && !startTimedOut && !disconnected) return;
    if (now - lastStreamConnectAttemptMs < STREAM_RECONNECT_RETRY_MS) return;

    Serial.printf("[CORE][RECONNECT] reason=%s rxAge=%lums conn=%d wifi=%d\n",
                  disconnected ? "closed" : (startTimedOut ? "start" : "stall"),
                  diagLastTcpRxMs == 0 ? 0UL : (unsigned long)(now - diagLastTcpRxMs),
                  client.connected(), WiFi.status());
    connectCameraStream();
}
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

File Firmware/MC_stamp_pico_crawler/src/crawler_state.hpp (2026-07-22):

#ifndef CRAWLER_STATE_HPP
#define CRAWLER_STATE_HPP

#include <stdint.h>

//Mode
#define INIT_MODE       0
#define AVERAGE_MODE    1
#define FLIGHT_MODE     2
#define PARKING_MODE    3

//Battery
#define BATTERY_VOLTAGE (3.7)
#define POWER_LIMIT 3.34
#define UNDER_VOLTAGE_COUNT 100

//etc
#define AVERAGENUM      800

typedef struct{
    float accx;
    float accy;
    float accz;
    float roll_rate;
    float pitch_rate;
    float yaw_rate;
    float roll_angel;
    float pitch_angle;
    float yaw_angle;
    float voltage;
    uint16_t bottom_tof_range;
}sensor_value_t;

typedef struct{
    volatile uint8_t mode=0;
    volatile uint8_t oldmode=0;
    volatile uint8_t loop=0;
}flag_t;

typedef struct{
    uint16_t loop=0;
    uint16_t offset=0;
    uint32_t counter=0;
}counter_t;

typedef struct{
    float elapsed_time;
    float old_elapsed_time;
    float interval_time;
    uint32_t start_time;
}times_t;

typedef struct{
    sensor_value_t sensor;
    flag_t flag;
    counter_t counter;
    times_t times;
} crawler_state_t;

extern crawler_state_t CrawlerState;

#endif

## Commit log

2026-07-20 Replace Stamp video feed with Stamp Pico crawler
    [main.cpp, main_loop.cpp, rc.cpp]
2026-07-20 Add MicroLink Crawler 3D printer data
    [chassis.f3d, chassis.stl, hinge_s.f3d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]
2026-07-21 Replace GC0308 AP firmware with gylo version
    [main.cpp]
2026-07-22 Update camera receiver and Atom joystick firmware
